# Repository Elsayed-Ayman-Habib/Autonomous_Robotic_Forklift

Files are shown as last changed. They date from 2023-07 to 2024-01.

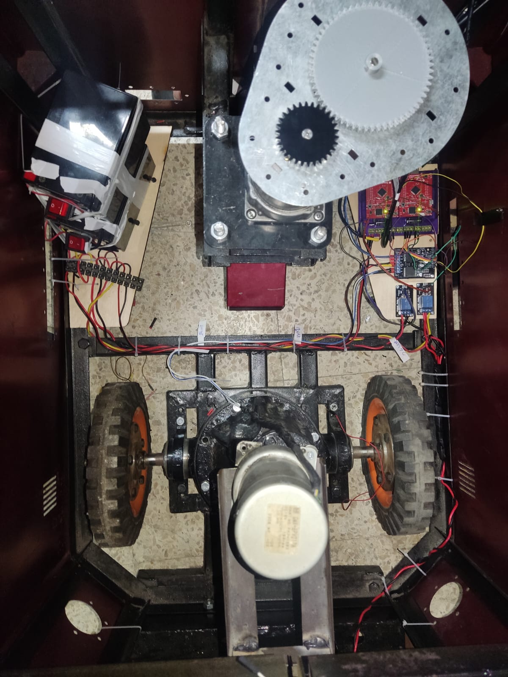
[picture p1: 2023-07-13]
Mechanical/photos/504c4e7d-c44a-4d6c-9fbc-8029b2791f7c.jpg

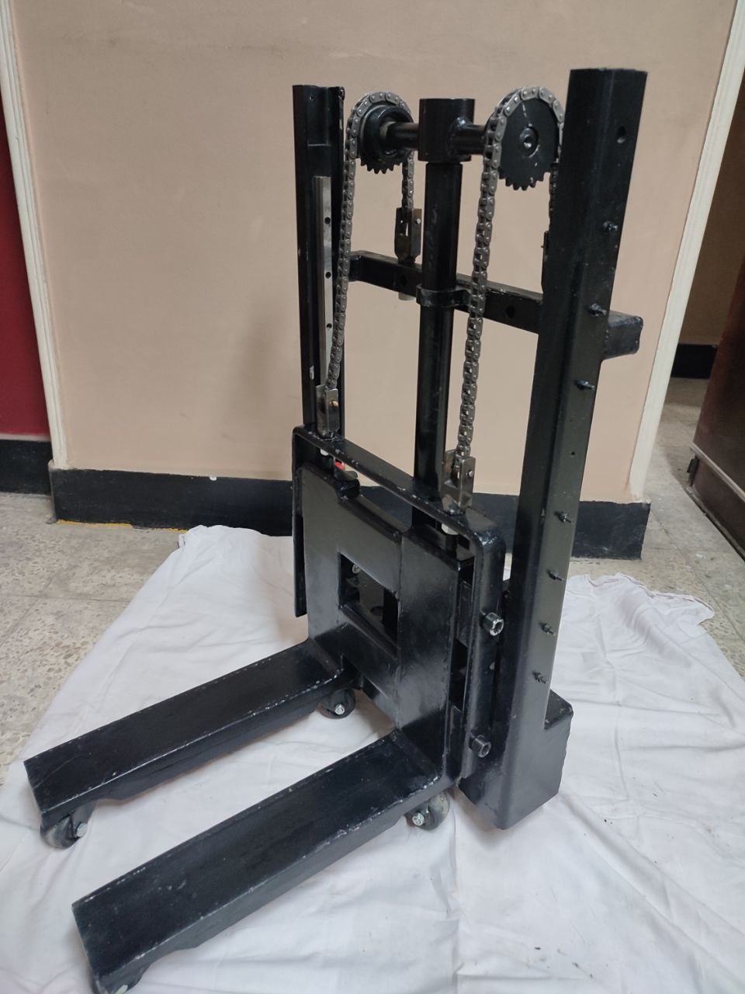
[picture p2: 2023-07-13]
Mechanical/photos/photo_2023-01-30_05-22-00.jpg

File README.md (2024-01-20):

# Autonomous_Robotic_Forklift

Our forklift prioritizes safety above all else. Its design incorporates precise sizes, tolerances, and detailed working drawings for every component. We conducted comprehensive stress analysis for optimal performance. The final product stands out with its appealing shape, exceptional finishing, and seamless assembly.

Our project involved an embedded system with one Arduino Mega microcontroller as data buffer between the Jetson TX2 and two Tiva-C boards. Following AUTOSAR standards, our system incorporated the MCAL, HAL, and APP drivers. The MCAL layer included functionalities such as DIO, PORT, ADC, PWM, INTCTRL, UART, and TIMERS, while the HAL layer focused on Encoder, Motor, and LED functionalities. The App layer featured a PID controller, parsing capabilities, and serialization techniques for efficient data transmission.

We integrated ROS for Navigation and Localization, leveraging sensor data to determine the robot's position and orientation. This framework empowered our robot to navigate complex environments with confidence, ensuring optimal path planning, obstacle avoidance, and efficient movement.

We employed computer vision techniques using a pretrained YOLO CNN for object detection and recognition. Our computer vision module included QR code detection and scanning using the zbar ROS package, enabling the robot to identify goal destinations for precise movements.

The successful integration of ROS for Navigation and Localization in our project has advanced our understanding of robotics and equipped us with the skills necessary to contribute to the future of autonomous systems. I am proud of my team's accomplishments and look forward to further exploring innovation in robotics, leveraging cutting-edge technologies like ROS to redefine human-robot interaction.

# Tutorial

### Hardware
- Nvidia Jetson TX2
- 2 Tiva-C
- Arduino Mega (as buffer)
- 2 Encoders and 2 DC motors
- Potentiometer
- Batteries (2 for system (24V-24A) - 1 for Jetson (12V-12A))
- YDLidar
- Kinect V1
- Linear Fork DC Motor
- VNH5019 DC Motor Driver
- relay module
- Emergency Stop Position

### Software
- JetPack 4.6 (For Jetson)
- Ubuntu 18.4 here.
- ROS Melodic

### 1. Setting up the Ubuntu Environment.
- 1. install sdk manager in your laptob
  2. read user guide from Nvidia jetson tx2 datasheet
  3. follow this video to complete the steps [Link of Video](https://youtu.be/Ucg5Zqm9ZMk)

### 2. Setting up the ROS repositories.
- By Opening a terminal and run the following command to configure the Ubuntu repositories:
```
sudo sh -c 'echo "deb http://packages.ros.org/ros/ubuntu $(lsb_release -sc) main" >/etc/apt/sources.list.d/ros-latest.list'
```
### 3. Setting up the ROS keys.
- By Downloading the ROS keyring and adding it to the system by running the following command:
```
curl -s https://raw.githubusercontent.com/ros/rosdistro/master/ros.asc | sudo apt-key add -
```
### 4. Updating the package lists.
- By Running the following command to update the package lists from the repositories:
```
sudo apt update
```
### 5. Desktop-Full Installation.
- ROS Melodic offers different installation options. For most users, the DesktopFull or Desktop installation is recommended as it includes the most commonly used packages for ROS development. Running the following command will install the Desktop-Full version:
```
sudo apt install ros-melodic-desktop-full
```
### 6. Initializing rosdep.
- By Running the following commands to initialize rosdep, which is used to install system dependencies for ROS packages:
```
sudo rosdep init rosdep update
```
### 7. Setting up the environment.
```
echo "source /opt/ros/melodic/setup.bash" >> ~/.bashrc source ~/.bashrc
```
### 8. Verifying the installation.
- By opening a new terminal and running the following command to check if ROS Melodic is properly installed:
```
rosversion -d
```
- The output should display melodic, confirming a successful installation

###  move_base ROS installation for Navigation stack.
- The installation commands :
```
Cd catkin_ws/src
Git clone https://github.com/ros-planning/navigation.git
```

### Teb_local_planner ROS installation. 
- The installation commands :
```
Cd catkin_ws/src
rosdep install teb_local_planner
Git clone https://github.com/rst-tu-dortmund/teb_local_planner.git
```

### robot_pose_ekf ROS installation.
- The installation commands :
```
sudo apt-get install ros-melodic-robot-pose-ekf
```

## AMCL ROS installation.
- The installation commands :
```
sudo apt-get install ros-melodic-amcl
```

### TF ROS installation.
- The installation commands:
```
Cd catkin_ws/src
Git clone https://github.com/ros/geometry
```

### installing Kinect v1 drivers and dependencies.
- Steps of installation :
 1. Install the dependencies:
```
sudo apt-get install git-core cmake freeglut3-dev pkg-config build-essential libxmu-dev libxi-dev libusb-1.0-0-dev
sudo apt-get install git-core cmake freeglut3-dev pkg-config build-essential libxmu-dev libxi-dev libusb-1.0-0-dev
```
- 2. Get the libfreenect repository from GitHub:
```
cd ~/catkin_ws/src
git clone git://github.com/OpenKinect/libfreenect.git
```
- 3. Make and install:
```
cd libfreenect
mkdir build
cd build
cmake -L ..
sudo make install
sudo ldconfig /usr/local/lib64
sudo adduser $USER video
sudo adduser $USER plugdev
```
- 4. adding some device rules:
```
sudo nano /etc/udev/rules.d/51-kinect.rules
```
- 5. generating files and running Kinect test:
```
python3 src/fwfetcher.py
sudo cp src/audios.bin /usr/local/share/libfreenect
freenect-micview
freenect-glview
```
- 6. running Kinect with ROS:
```
cd catkin_ws
catkin_make
source devel/setup
roslaunch freenect_launch freenect.launch depth_registration:=true
```

# To launch our project.
- follow this commands:
```
roslaunch freenect_launch freenect.launch depth_registration:=true
roslaunch teb_local_planner_tutorials robot_carlike_in_stage.launch #the package launch
```
# Link of Report & Presentation and Video 
- https://drive.google.com/drive/folders/1iCM8DTQ_ik3RJ6Gb64cmEPBjMHCCbpft?usp=sharing

# Final Product 


# BY:
Abdelrahman Mahmoud Ehab
Abdelrahman Mostafa Mahmoud
Abdelrhman Motawea Ali     
Abdelrahman Omar Abdelhalem  
Anas Ahmed Talaat                
El Sayed Ayman El Sayed     
Mahmoud Ayman Abdelaziz     
Mahmoud Tariq Mahmoud      
Mahmoud Nassef Mohamed      

# Thanks our Team


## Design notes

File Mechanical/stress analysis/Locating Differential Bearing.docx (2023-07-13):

Forklift Graduation Team Ainshams University January 15, 2023

Locating Differential Bearing

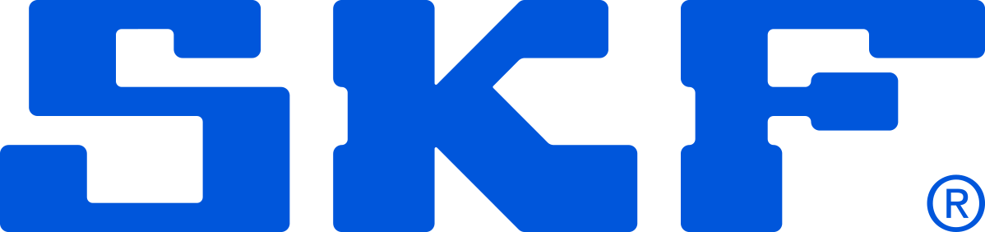
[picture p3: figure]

SKF Bearing Select Report 1.3-186

1. Abstract

Deep groove ball bearing

SKF Explorer

Calculation overview

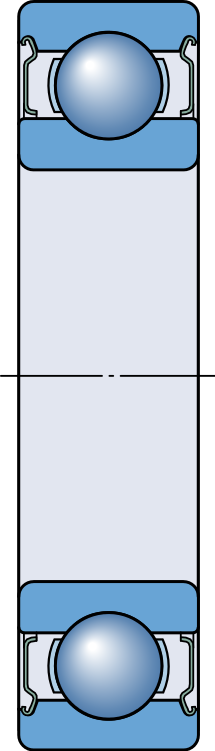
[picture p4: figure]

| Bearing | rating | life | Static safety factor | Frictional moment | Power loss
Designation | Basic | SKF life | | | Total
| L10h (h) | L10mh (h) | | S0 | M (Nmm) | Ploss (W)
6005-2Z (https://www.skf.com/productcatalogue?language=en&system=metric&designation=6005-2Z) | 5540 | 3880 | | 1.77 | 129 | 1.4

Consideration

All calculated values are best estimates resulting from the input data and assumptions, and well-recognized data sources, and well-established calculation methods.

SKF follows standards and methods suggested by Greenhouse Gas Protocol for CO2 estimates. For details about data, methods, and assumptions used, follow the link below.

If you intend to use these values for decision making, contact SKF for more details and correct interpretation of calculation results. The values calculated by SKF Bearing Select should not be compared with values obtained from other tools or sources, unless you are confident about the data sources, methods and assumptions used. More info (https://skf.com/group/support/engineering-tools/bearing-select/info-about-co2-est)

Consideration

Grease consumption is almost zero, therefore CO2 emissions are not calculated.

Consideration

The calculated SKF rating life L10 mh is shorter than the period of interest.

Consideration

Low viscosity ratio k, reduced asperity contact. It is recommended to select a higher viscosity lubricant or improve cooling. It is not appropriate to look at basic rating life only. Instead use SKF rating life method. Recommended to use anti-wear (AW) or extreme pressure (EP) additives to reduce wear More info (https://www.skf.com/group/products/rolling-bearings/principles-of-rolling-bearing-selection/bearing-selection-process/bearing-size/size-selection-based-on-rat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)

Rotating ring Inner ring rotation

Maximum temperature is used for calculating the actual viscosity, kappa, aSKF and SKF rating life. Mean temperature is used for calculating bearing friction and power loss.

2.2. Loads, Speed and Temperature

2. Input

2.1. Bearing data

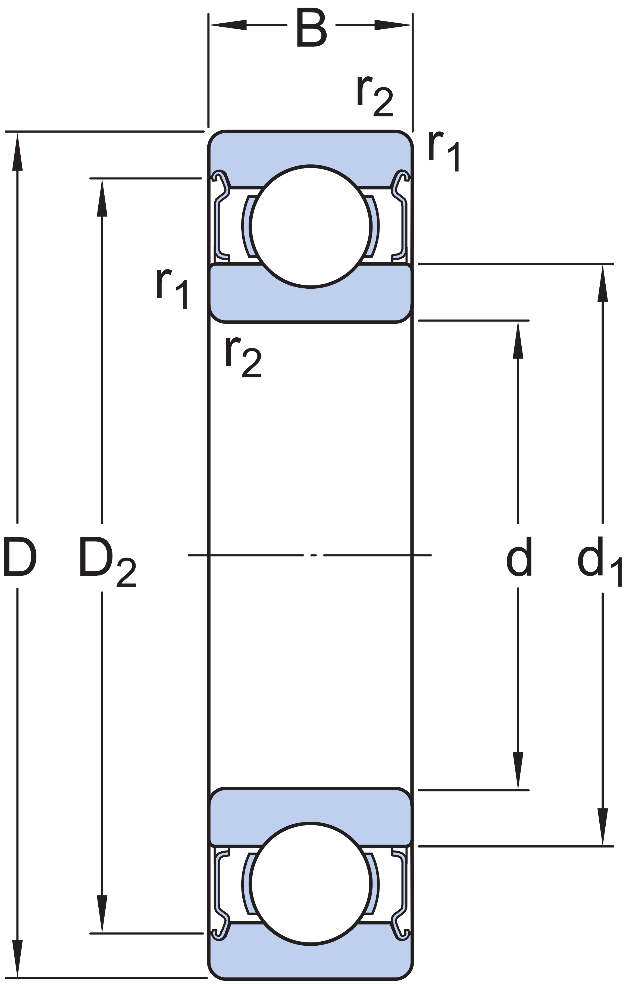
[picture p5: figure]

| | Principal | dimensions | | Basic load | ratings | Fatigue load limit | Speed ratings | | Cleara nce class
Designation | Bearing type | | | | Dynamic | Static | | Reference | Limiting
| | d (mm) | D (mm) | B (mm) | C (kN) | C0 (kN) | Pu (kN) | nref (r/min) | nlim (r/min)
6005-2Z (https://www.skf.com/productcatalogue?language=en&system=metric&designation=6005-2Z) | Deep ball groove bearing | 25.0 | 47.0 | 12.0 | 11.9 | 6.55 | 0.275 | 32000.0 | 16000.0 | Norma l

Forces | | | | | | Speed | Temperature | | | | Case weight
Radial | | ( Fr | ) | (kN) | Axial ( Fa ) (kN) | (r/min) | Inner | ring | (°C) | Outer ring (°C)
LC1 | 3.7 | 0.0 | | | | 100.0 | 30 | 30 | | | 1

2.3. Lubrication
| | | Lubricant | Effective EP additives | Contamination
| | Designation | Name | | Method | Cleanliness / Factor
| 6005-2Z (https://www.skf.com/productcatalogue?language=en&system=metric&designation=6005-2Z) | | MT47 | False | Detailed guidelines | High cleanliness

3.2. Bearing minimum load

3.3. Adjusted reference speed

2.4. CO2 emissions settings
| Designation | Input energy mix manually | Geographical location | Period of interest [Years] | Time operational [%]
| 6005-2Z (https://www.skf.com//opcprodlink.html?lang=language_Report&imperial=metric&prodid=6005-2Z) | False | European Union | 1 | 100

2.5. Fits and tolerances
| | | Requirements | Tolerance | Class | Calculated interference | Include Smoothing
| | Designation | Guidance | Housing | Shaft
| 6005-2Z (https://www.skf.com/productcatalogue?language=en&system=metric&designation) | | False | G7 | g6 | True | True

3. Results

3.1. Loads & static safety
| | | Load | ratio | Static safety factor | Equivalent dynamic load | Equivalent static load
| | Designation | C/P | S0 | | P (kN) | P0 (kN)
| 6005-2Z (https://www.skf.com/productcatalogue?language=en&system=metric&designation=6005-2Z) | | 3.22 | 1.77 | | 3.7 | 3.7

| | Reaction | forces Minimum load
| Designation | Radial | Axial | | Requirements
| | Fr (kN) | Fa (kN) | Frm (kN) | met?
6005-2Z (https://www.skf.com/productcatalogue?language=en&system=metric&designation=6005-2Z) | | 3.7 | 0.0 | 0.0177 | yes

| | Adjusted reference speed | Adjustment | factors
| Designation | | For bearing | load | P | For oil viscosity
| | nar (r/min) | fp | fv
6005-2Z (https://www.skf.com/productcatalogue?language=en&system=metric&designation=6005-2Z) | | 13700 | 0.41 | 1.03

3.4. Lubrication conditions

3.5. Bearing rating life

3.7. Bearing frequencies

| | Frictional moment Friction sources | | | | | | | | Power loss
| Designation | Total | At start and 20-30°C zero speed | | Rolling | Sliding | Seals | | Drag loss
| | M (Nmm) | Mstart | (Nmm) | Mrr (Nmm) | Msl (Nmm) | Mseal | (Nmm) | Mdrag (Nmm) | Ploss (W)
6005-2Z (https://www.skf.com/productcatalogue?language=en&system=metric&designation=6005-2Z) | | 129 | 195 | 11.1 | | 118 | 0 | 0 | | 1.4

| | Operating viscosity | | | Viscosity ratio
| Designation | Actual | Rated | Rated @ 40 °C
| | ν (mm^2/s) | ν1 (mm^2/s) | νref (mm^2/s) | κ
6005-2Z (https://www.skf.com/productcatalogue?language=en&system=metric&designation=6005-2Z) | | 128 | 147 | 85.0 | 0.87

| | Bearing | rating | life | SKF life modification factor | Contamination factor
| Designation | Basic | SKF
| | L10h (h) | L10mh (h) | | askf | ηc
6005-2Z (https://www.skf.com/productcatalogue?language=en&system=metric&designation=6005-2Z) | | 5540 | 3880 | | 0.7 | 0.45

Consideration

Low viscosity ratio k, reduced asperity contact. It is recommended to select a higher viscosity lubricant or improve cooling. It is not appropriate to look at basic rating life only. Instead use SKF rating life method. Recommended to use anti-wear (AW) or extreme pressure (EP) additives to reduce wear More info (https://www.skf.com/group/products/rolling-bearings/principles-of-rolling-bearing-selection/bearing-selection-process/bearing-size/size-selection-based-on-rat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)

3.6. Bearing friction & power loss

| Rotational frequencies | | | | | | | Frequency of over-rolling
Designation | Inner | ring | Outer ring | Rolling & cage | element | set | Rolling element about its axis | Point on inner ring | Point on outer ring | Rolling | element
| fi (Hz) | fe (Hz) | | fc (Hz) | fr (Hz) | | | fip (Hz) | fep (Hz) | frp (Hz)
6005-2Z (https://www.skf.com/productcatalogue?language=en&system=metric&designation=6005-2Z) | 1.667 | 0.0 | | 0.677 | 4.29 | | | 9.895 | 6.772 | 8.58

* Value is not designation specific, but based on bearing mass

3.8. Estimation of CO2 emissions over period of interest

| Shaft outer | diameter | Bearing bore | | Bearing outer diameter | | Housing bore | | Smoothing
Designation | Minimum | Maximum | Minimum | Maximum | Minimum | Maximum | Minimum | Maximum | Shaft an bearing | d bore | Bearing outer ring and housing
| (μm) | (μm) | (μm) | (μm) | (μm) | (μm) | (μm) | (μm) | (μm) | (μm)
6005-2Z (https://www.skf.com/productcatalogue?language=en&system=metric&designation=6005-2Z) | -20 | -7 | -10 | 0 | -11 | 0 | 9 | 34 | 7 | 12

| | CO2 emissions caused by bearing production | CO2 emissions during bearing operation - over period of interest | | | | Resources consumed during bearing operation - over period of interest
| Designation | | Frictio power | nal loss | Grease c onsumpt ion | Sum of CO2 o during peration | Energy | Grease
| | kg of CO2 | kg of | CO2 | kg of CO2 | kg of CO2 | kWh | kg
6005-2Z (https://www.skf.com/productcatalogue?language=en&system=metric&designation=6005-2Z) | | *0.3 (Learn more) (https://skf.com/group/support/engineering-tools/bearing-select/info-about-co2-est#cid-596137) | 5.5 | 0.0 | | 5.5 | 11.9 | 0.0

Consideration

All calculated values are best estimates resulting from the input data and assumptions, and well-recognized data sources, and well-established calculation methods.

SKF follows standards and methods suggested by Greenhouse Gas Protocol for CO2 estimates. For details about data, methods, and assumptions used, follow the link below.

If you intend to use these values for decision making, contact SKF for more details and correct interpretation of calculation results. The values calculated by SKF Bearing Select should not be compared with values obtained from other tools or sources, unless you are confident about the data sources, methods and assumptions used. More info (https://skf.com/group/support/engineering-tools/bearing-select/info-about-co2-est)

Consideration

Grease consumption is almost zero, therefore CO2 emissions are not calculated.

Consideration

The calculated SKF rating life L10 mh is shorter than the period of interest.

3.9. Fits and tolerances
| Note Typically, it is not sufficient to use an interference fit alone to axially locate a bearing ring on a cylindrical seat.

3.9.1. Tolerances

Consideration

For the tolerances calculation, the normal tolerance for the bearing bore and outer diameter is used.

3.9.2. Fits, Probable Interference (+) / Clearance (-)

| | Shaft | | | Housing
| Designation | Probable minimum | Middle | Probable maximum | Probable minimum | Middle | Probable maximum
| | (μm) | (μm) | (μm) | (μm) | (μm) | (μm)
6005-2Z (https://www.skf.com/productcatalogue?language=en&system=metric&designation=6005-2Z) | | -24 | -16 | -7 | -53 | -39 | -25

SKF Bearing Select 6 2023-01-15 16:31:43

LIMITED WARRANTY : The SKF Bearing Select software tool of the SKF Company supports the calculation and selection of bearings.

This software is provided 'as is' with out any warranty of any sort, implicitly as well as explicitly.

Please note that the obtained results can be affected by many external parameters and/or the quality of the assumptions taken into account. The results obtained using this software must be validated by the user who accepts the fact that the use of this software and the exploitation of the obtained results are under the user's entire and sole responsibility.

® SKF is a registered trademark of the SKF Group. © SKF Group 2022.

SKF Bearing Select 1 2023-01-15 16:31:43 This report was produced with SKF Bearing Select software. Please note the limited warranty, shown at the bottom of the last page of this report ® SKF is a registered trademark of the SKF Group. © SKF Group 2022.

SKF Bearing Select 2 2023-01-15 16:31:43 This report was produced with SKF Bearing Select software. Please note the limited warranty, shown at the bottom of the last page of this report ® SKF is a registered trademark of the SKF Group. © SKF Group 2022.

SKF Bearing Select Report 1.3-186

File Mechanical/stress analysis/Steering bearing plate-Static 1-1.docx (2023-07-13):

# Loads and Fixtures

Fixture name | Fixture Image | Fixture Details

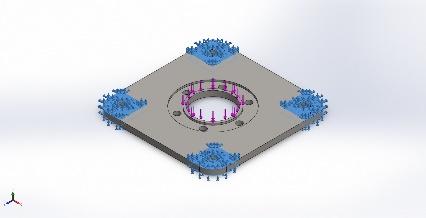
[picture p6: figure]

Fixed-1 | | Entities: 8 face(s) Type: Fixed Geometry

Resultant Forces

Components | X | Y | Z | Resultant
Reaction force(N) | -0.16123 | 2,499.99 | -0.136569 | 2,499.99
Reaction Moment(N.m) | 0 | 0 | 0 | 0

Load name | Load Image | Load Details

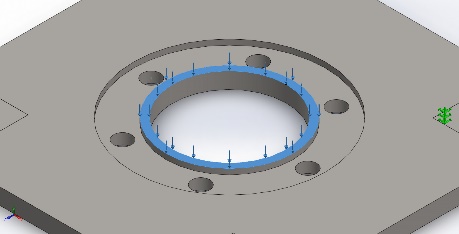
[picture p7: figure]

Force-1 | | Entities: 1 face(s) Type: Apply normal force Value: 2,500 N

# Resultant Forces :

## Reaction forces :

Selection set | Units | Sum X | Sum Y | Sum Z | Resultant
Entire Model | N | -0.16123 | 2,499.99 | -0.136569 | 2,499.99

## Reaction Moments :

Selection set | Units | Sum X | Sum Y | Sum Z | Resultant
Entire Model | N.m | 0 | 0 | 0 | 0

## Free body forces :

Selection set | Units | Sum X | Sum Y | Sum Z | Resultant
Entire Model | N | 0.19792 | 1.8234 | 0.393877 | 1.87593

## Free body moments :

Selection set | Units | Sum X | Sum Y | Sum Z | Resultant
Entire Model | N.m | 0 | 0 | 0 | 1e-33

# Study Results

Name | Type | Min | Max
Stress1 | VON: von Mises Stress | 4.504e-04N/mm^2 (MPa) Node: 9706 | 1.010e+02N/mm^2 (MPa) Node: 20652

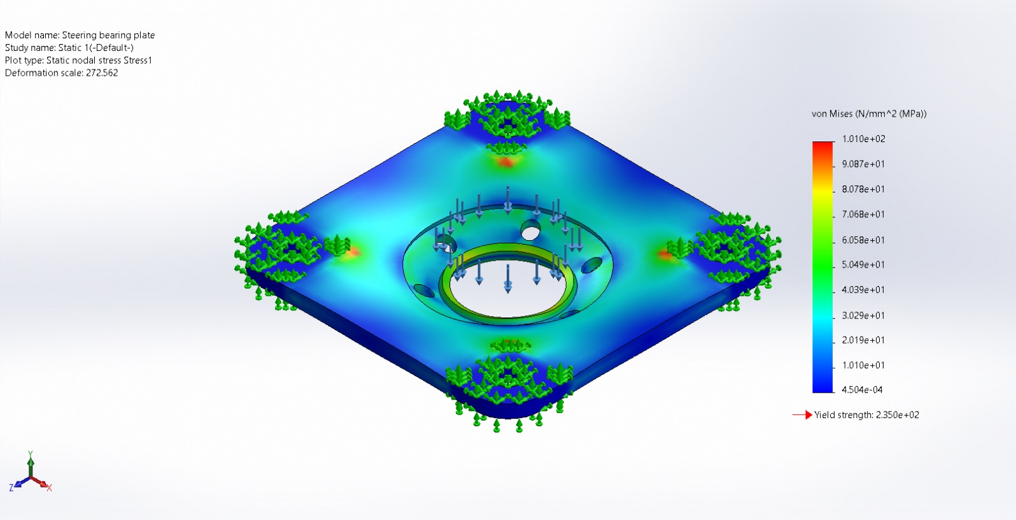
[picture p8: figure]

Steering bearing plate-Static 1-Stress-Stress1

Name | Type | Min | Max
Displacement1 | URES: Resultant Displacement | 0.000e+00mm Node: 1 | 4.806e-02mm Node: 363

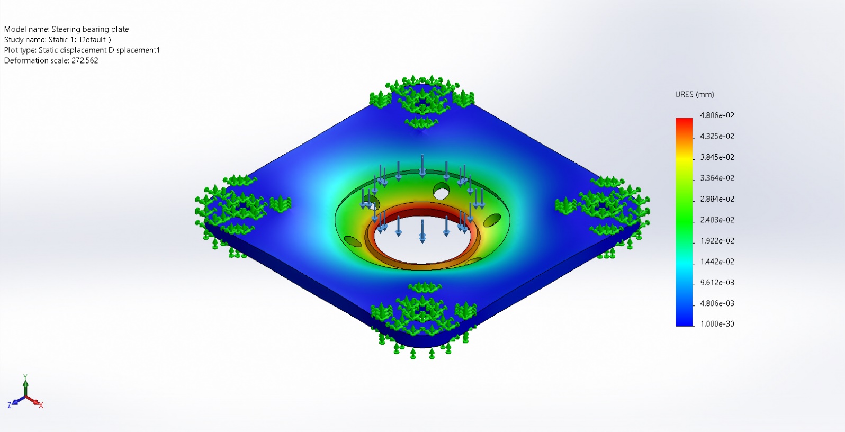
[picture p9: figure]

Steering bearing plate-Static 1-Displacement-Displacement1

Name | Type | Min | Max
Strain1 | ESTRN: Equivalent Strain | 1.795e-09 Element: 3587 | 2.801e-04 Element: 12603

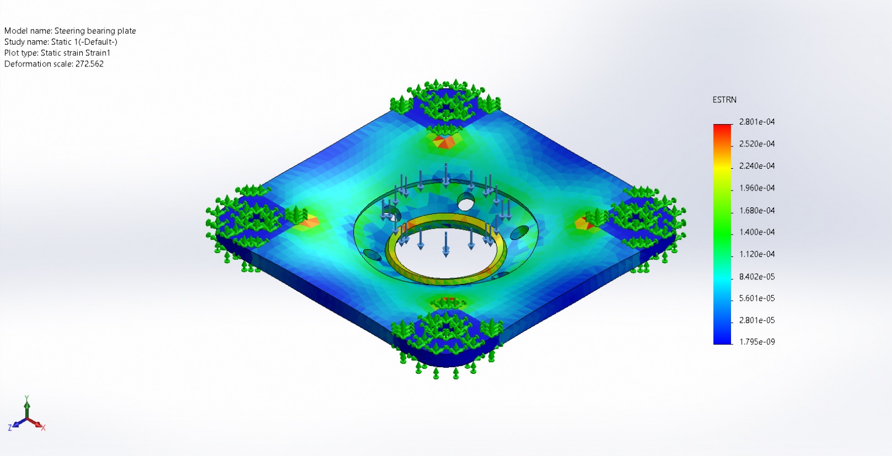
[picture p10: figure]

Steering bearing plate-Static 1-Strain-Strain1

Analyzed with SOLIDWORKS Simulation Simulation of Steering bearing plate 16

Analyzed with SOLIDWORKS Simulation Simulation of Steering bearing plate 1

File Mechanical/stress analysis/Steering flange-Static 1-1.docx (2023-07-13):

# Loads and Fixtures

Fixture name | Fixture Image | Fixture Details

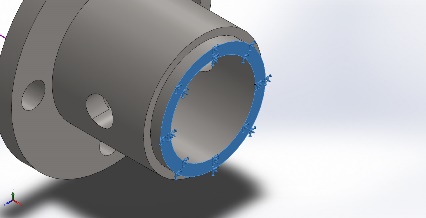
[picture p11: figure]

Fixed-1 | | Entities: 1 face(s) Type: Fixed Geometry

Resultant Forces

Components | X | Y | Z | Resultant
Reaction force(N) | -2,500.02 | 0.0202789 | -0.0246192 | 2,500.02
Reaction Moment(N.m) | 0 | 0 | 0 | 0

Load name | Load Image | Load Details

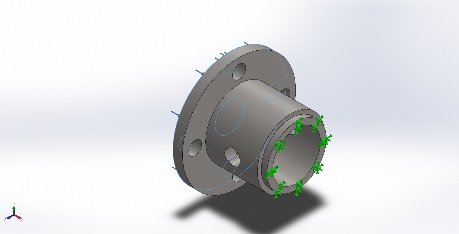
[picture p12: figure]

Force-1 | | Entities: 1 face(s) Type: Apply normal force Value: 2,500 N

# Resultant Forces :

## Reaction forces :

Selection set | Units | Sum X | Sum Y | Sum Z | Resultant
Entire Model | N | -2,500.02 | 0.0202789 | -0.0246192 | 2,500.02

## Reaction Moments :

Selection set | Units | Sum X | Sum Y | Sum Z | Resultant
Entire Model | N.m | 0 | 0 | 0 | 0

## Free body forces :

Selection set | Units | Sum X | Sum Y | Sum Z | Resultant
Entire Model | N | 0.047928 | 0.103331 | 0.163004 | 0.198859

## Free body moments :

Selection set | Units | Sum X | Sum Y | Sum Z | Resultant
Entire Model | N.m | 0 | 0 | 0 | 1e-33

# Study Results

Name | Type | Min | Max
Stress1 | VON: von Mises Stress | 1.890e-01N/mm^2 (MPa) Node: 26868 | 2.419e+01N/mm^2 (MPa) Node: 17132

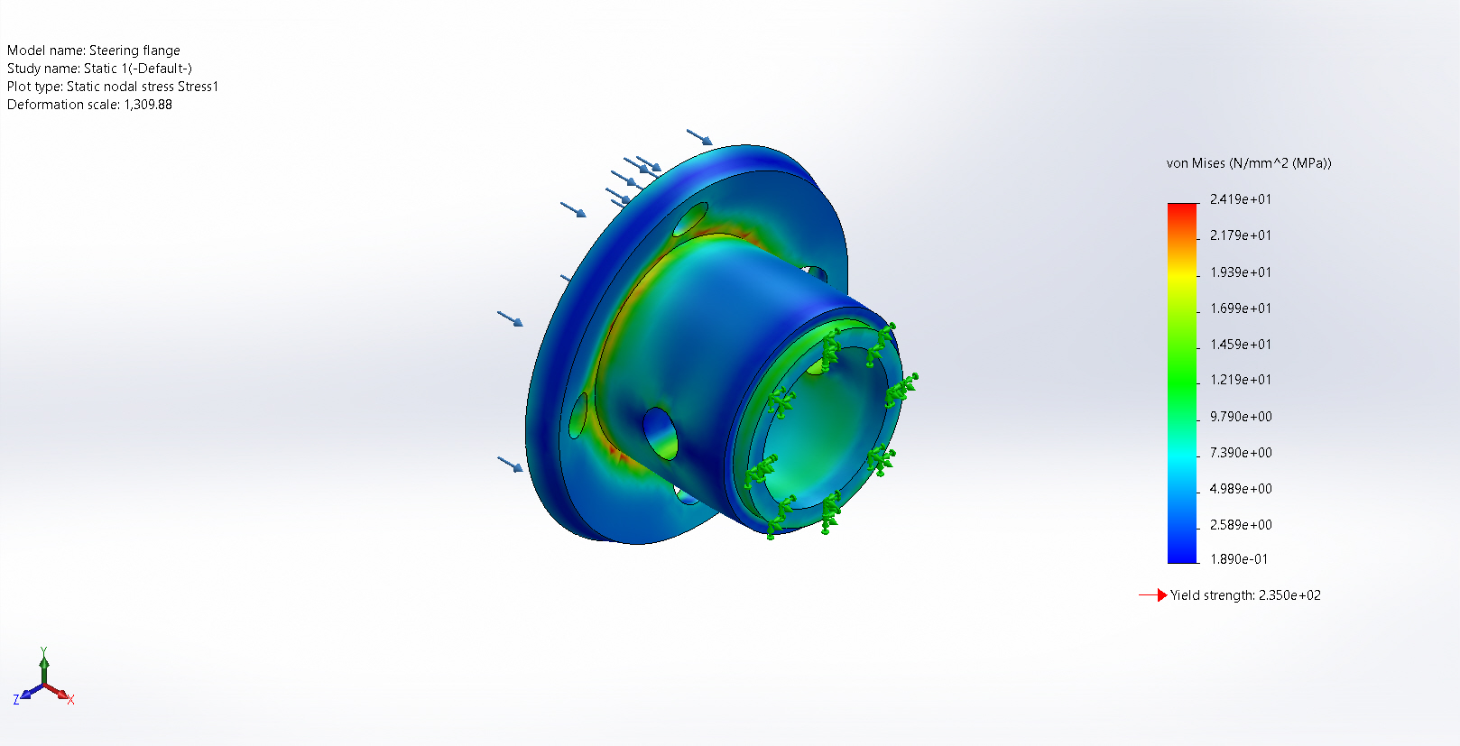
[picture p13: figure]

Steering flange-Static 1-Stress-Stress1

Name | Type | Min | Max
Displacement1 | URES: Resultant Displacement | 0.000e+00mm Node: 785 | 4.579e-03mm Node: 25194

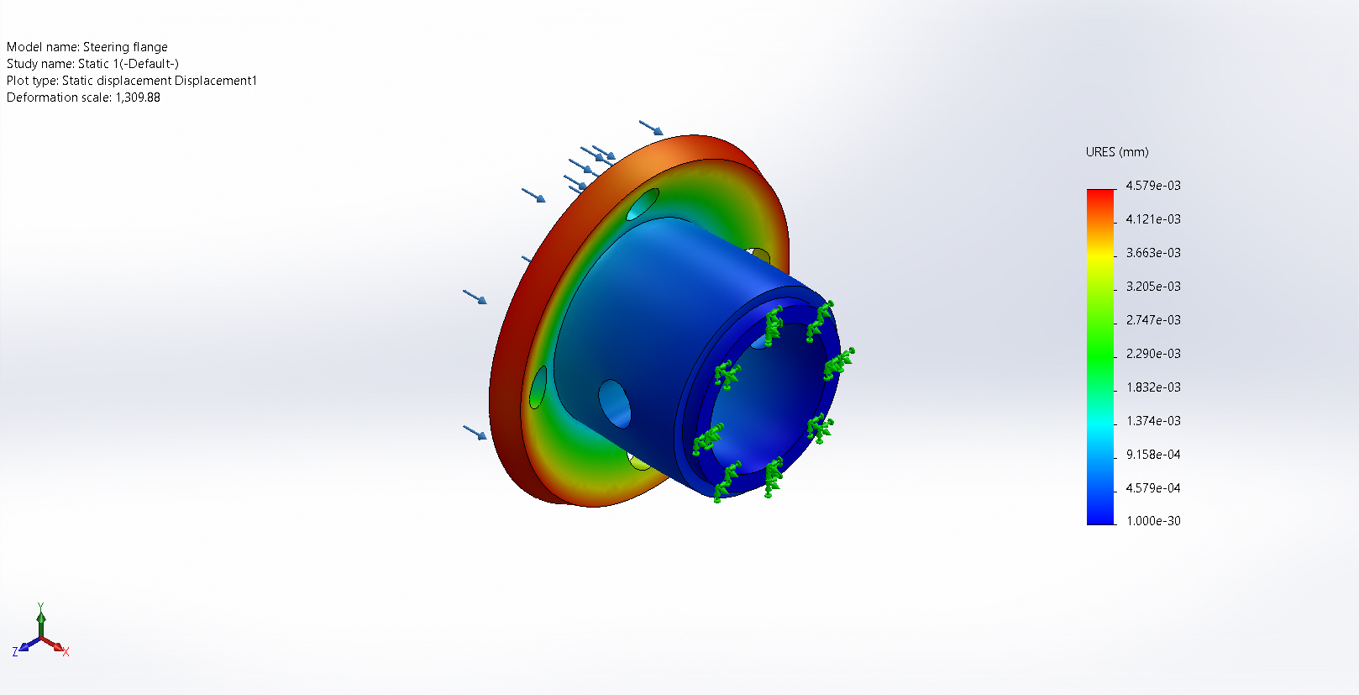
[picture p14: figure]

Steering flange-Static 1-Displacement-Displacement1

Name | Type | Min | Max
Strain1 | ESTRN: Equivalent Strain | 1.079e-06 Element: 2479 | 9.309e-05 Element: 9469

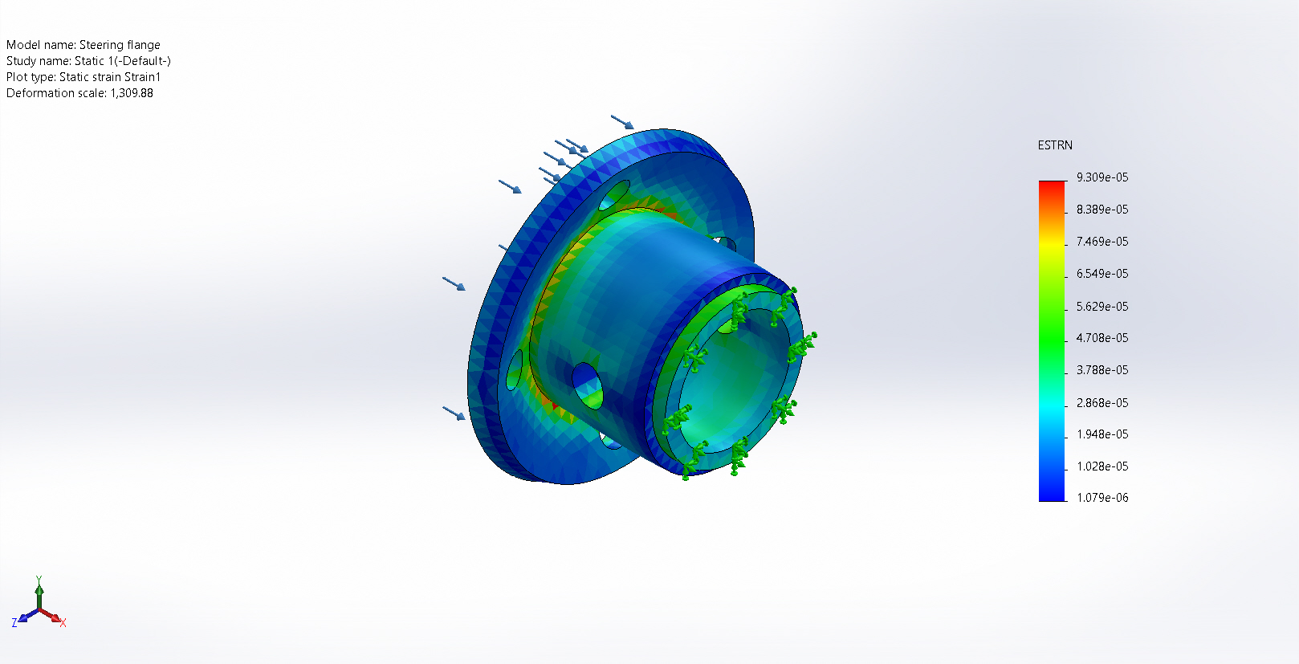
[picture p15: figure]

Steering flange-Static 1-Strain-Strain1

Analyzed with SOLIDWORKS Simulation Simulation of Steering flange 16

Analyzed with SOLIDWORKS Simulation Simulation of Steering flange 1

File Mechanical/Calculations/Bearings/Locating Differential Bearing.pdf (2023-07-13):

Forklift Graduation Team

Ainshams University

January 15, 2023

Locating Differential Bearing

2023-01-15 16:31:43

SKF Bearing Select Report 1.3-186

# 1. Abstract

## Calculation overview

Deep groove ball bearing

SKF Explorer

Bearing rating life | Static safety
factor

Frictional
| | | | moment | Power loss
Designation | Basic | SKF life | | Total
| L
| 10h (h) | L
| | 10mh (h) | S
| | | 0 | M (Nmm) | P loss (W)
6005-2Z (https://www.skf.com/productcatalogue?language=en&system=metric&designation=6005-2Z) | 5540 | 3880 | 1.77 | 129 | 1.4

### Consideration

All calculated values are best estimates resulting from the input data and assumptions, and well-recognized data sources, and well-established calculation methods.
SKF follows standards and methods suggested by Greenhouse Gas Protocol for CO2

estimates.
For details about data, methods, and assumptions used, follow the link below.
If you intend to use these values for decision making, contact SKF for more details and correct interpretation of calculation results. The values calculated by SKF Bearing Select should not be compared with values obtained from other tools or sources, unless you are confident about the data sources, methods and assumptions used. More info (https://skf.com/group/support/engineering-tools/bearing-select/info-about-co2-est)

### Consideration

Grease consumption is almost zero, therefore CO2

emissions are not calculated.

### Consideration

The calculated SKF rating life L10 mh is shorter than the period of interest.

### Consideration

Low viscosity ratio k, reduced asperity contact. It is recommended to select a higher viscosity lubricant or improve cooling. It is not appropriate to look at basic rating life only. Instead use SKF rating life method. Recommended to use anti-wear (AW) or extreme pressure (EP) additives to reduce wear More info (https://www.skf.com/group/products/rolling-bearings/principles-of-rolling-bearing-selection/bearing-selection-process/bearing-size/size-selection-based-on-rat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)

SKF Bearing Select | 1

This report was produced with SKF Bearing Select software. Please note the limited warranty, shown at the bottom of the last page of this report
| ® SKF is a registered trademark of the SKF Group. © SKF Group 2022.

2023-01-15 16:31:43

# 2. Input

## 2.1. Bearing data

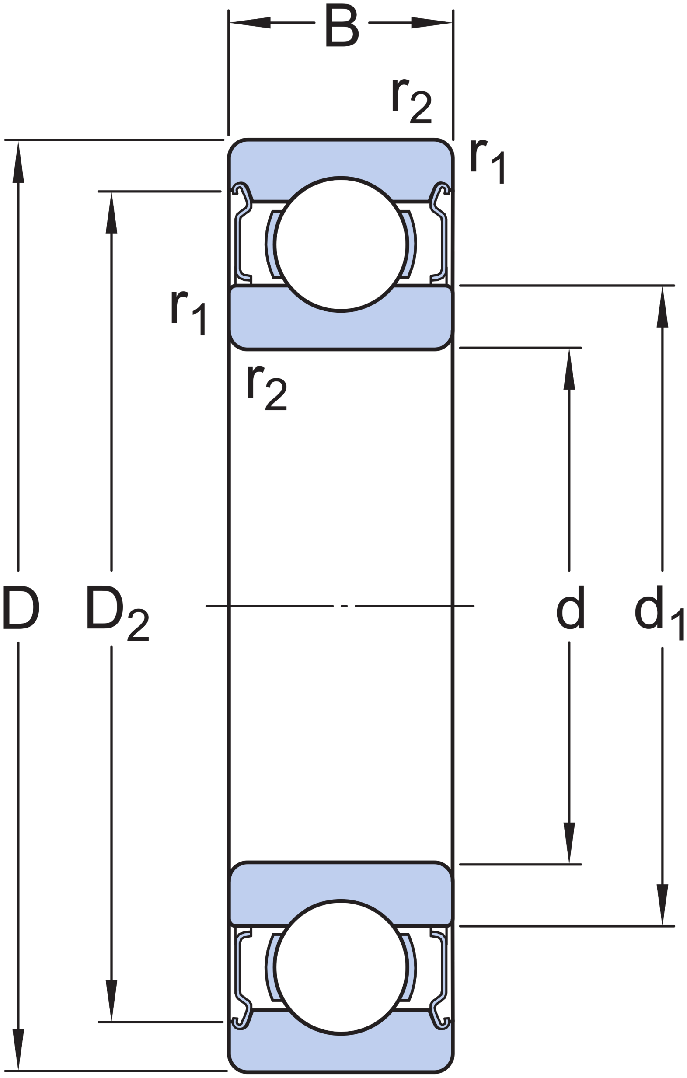
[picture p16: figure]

Principal dimensions | Basic load ratings | Fatigue load
| | | | | limit | Speed ratings | | Cleara nce class
Designation | Bearing
type | Dynamic | Static | Reference | Limiting
d (mm) | D (mm) | B (mm) | C (kN) | C
| | | | 0
| | | | (kN) | P u
| | | | | (kN) | n
| | | | | | ref (r/min) | n lim (r/min)

6005-2Z (https://www.skf.com/productcatalogue?language=en&system=metric&designation=6005-2Z)

Deep
groove ball
bearing
25.0 | 47.0 | 12.0 | 11.9 | 6.55 | 0.275 | 32000.0 | 16000.0 | Norma l

## 2.2. Loads, Speed and Temperature

Rotating ring | | Inner ring rotation
| Forces | | Speed | Temperature | | Case weight
| Radial ( F
r

) (kN) Axial ( F
a
) (kN) | (r/min) | Inner ring (°C) | Outer ring (°C)
LC1 | 3.7 | 0.0 | 100.0 | 30 | 30 | 1

Maximum temperature is used for calculating the actual viscosity, kappa, aSKF and SKF rating life.

Mean temperature is used for calculating bearing friction and power loss.

## 2.3. Lubrication

Lubricant | Effective EP
| | | additives | Contamination
Designation | Name | Method | Cleanliness / Factor
6005-2Z (https://www.skf.com/productcatalogue?language=en&system=metric&designation=6005-2Z) | MT47 | False | Detailed guidelines | High cleanliness
SKF Bearing Select | 2

This report was produced with SKF Bearing Select software. Please note the limited warranty, shown at the bottom of the last page of this report

2023-01-15 16:31:43

2.4. CO2

## emissions settings

Designation | Input energy mix manually | Geographical location | Period of interest [Years] | Time operational [%]
6005-2Z (https://www.skf.com//opcprodlink.html?lang=language_Report&imperial=metric&prodid=6005-2Z) | False | European Union | 1 | 100

## 2.5. Fits and tolerances

| Requirements | Tolerance Class | | Calculated
| | | | interference | Include Smoothing
Designation | Guidance | Housing | Shaft
6005-2Z (https://www.skf.com/productcatalogue?language=en&system=metric&designation=) | False | G7 | g6 | True | True

# 3. Results

## 3.1. Loads & static safety

| Load ratio | Static safety
| | factor | Equivalent dynamic load | | Equivalent static load
Designation | C/P | S
0
P (kN) | P
0

(kN)

6005-2Z (https://www.skf.com/productcatalogue?language=en&system=metric&designation=6005-2Z) | 3.22 | 1.77 | 3.7 | 3.7

## 3.2. Bearing minimum load

| Reaction forces | Minimum load
Designation | Radial | Axial | Requirements

F
r
(kN) | F
a
(kN) | F
rm
(kN) | met?
6005-2Z (https://www.skf.com/productcatalogue?language=en&system=metric&designation=6005-2Z) | 3.7 | 0.0 | 0.0177 | yes

## 3.3. Adjusted reference speed

| Adjusted reference
| speed | Adjustment factors
Designation | | For bearing load P | | For oil viscosity
| n
| ar
| (r/min) | f
p

f
v
6005-2Z (https://www.skf.com/productcatalogue?language=en&system=metric&designation=6005-2Z) | 13700 | 0.41 | 1.03
SKF Bearing Select | 3

This report was produced with SKF Bearing Select software. Please note the limited warranty, shown at the bottom of the last page of this report

2023-01-15 16:31:43

## 3.4. Lubrication conditions

Operating viscosity | Viscosity ratio
Designation | Actual | | Rated | Rated @ 40 °C
ν (mm^2/s) | ν
1
(mm^2/s) | ν
ref (mm^2/s) | κ
6005-2Z (https://www.skf.com/productcatalogue?language=en&system=metric&designation=6005-2Z) | 128 | 147 | 85.0 | 0.87

## 3.5. Bearing rating life

Bearing rating life | SKF life modification
factor | Contamination factor
Designation | Basic | | SKF
| L
10h (h) | L
10mh (h) | a
| | | skf | | η
| | | | | c
6005-2Z (https://www.skf.com/productcatalogue?language=en&system=metric&designation=6005-2Z) | 5540 | 3880 | 0.7 | 0.45

### Consideration

Low viscosity ratio k, reduced asperity contact. It is recommended to select a higher viscosity lubricant or improve cooling. It is not appropriate to look at basic rating life only. Instead use SKF rating life method. Recommended to use anti-wear (AW) or extreme pressure (EP) additives to reduce wear More info (https://www.skf.com/group/products/rolling-bearings/principles-of-rolling-bearing-selection/bearing-selection-process/bearing-size/size-selection-based-on-rat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)

## 3.6. Bearing friction & power loss

Frictional moment | Friction sources | Power
| | | | | | | loss
Designation | Total | At start
20-30°C and
zero speed
| | | Rolling | Sliding | Seals | Drag loss
M (Nmm) | Mstart (Nmm) | Mrr
(Nmm) | Msl (Nmm) | Mseal (Nmm) | Mdrag (Nmm) | P
| | | | | | | loss (W)
6005-2Z (https://www.skf.com/productcatalogue?language=en&system=metric&designation=6005-2Z) | 129 | 195 | 11.1 | 118 | 0 | 0 | 1.4

## 3.7. Bearing frequencies

Rotational frequencies | Frequency of over-rolling
Designation | Inner ring | Outer ring | Rolling element set
| | | & cage | Rolling element
| | | | about its axis | Point on
| | | | | inner ring | Point on
| | | | | | outer ring | Rolling element
| f
| i
| (Hz) | f
| | e
| | (Hz) | f
| | | c
| | | (Hz) | f
| | | | r
| | | | (Hz) | f
| | | | | ip (Hz) | f
| | | | | | ep
| | | | | | (Hz) | f
| | | | | | | rp (Hz)
6005-2Z (https://www.skf.com/productcatalogue?language=en&system=metric&designation=6005-2Z) | 1.667 | 0.0 | 0.677 | 4.29 | 9.895 | 6.772 | 8.58
SKF Bearing Select | 4

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

2023-01-15 16:31:43

## 3.8. Estimation of CO2

## emissions over period of interest

CO2

emissions caused
by bearing production

CO2

emissions during bearing
operation - over period of interest

Resources consumed during
bearing operation - over period of interest
Designation | Frictional
power loss

Grease c
onsumpt
ion

Sum of
CO2
during o
peration
Energy | Grease

kg of CO2

kg of CO2

kg of
CO2

kg of
CO2
kWh | kg
6005-2Z (https://www.skf.com/productcatalogue?language=en&system=metric&designation=6005-2Z) | *
0.3 (Learn more) (https://skf.com/group/support/engineering-tools/bearing-select/info-about-co2-est#cid-596137) | 5.5 | 0.0 | 5.5 | 11.9 | 0.0

*
Value is not designation specific, but based on bearing mass

### Consideration

All calculated values are best estimates resulting from the input data and assumptions, and well-recognized data sources, and well-established calculation methods.
SKF follows standards and methods suggested by Greenhouse Gas Protocol for CO2

estimates.
For details about data, methods, and assumptions used, follow the link below.
If you intend to use these values for decision making, contact SKF for more details and correct interpretation of calculation results. The values calculated by SKF Bearing Select should not be compared with values obtained from other tools or sources, unless you are confident about the data sources, methods and assumptions used. More info (https://skf.com/group/support/engineering-tools/bearing-select/info-about-co2-est)

### Consideration

Grease consumption is almost zero, therefore CO2

emissions are not calculated.

### Consideration

The calculated SKF rating life L10 mh is shorter than the period of interest.

## 3.9. Fits and tolerances

### Note

Typically, it is not sufficient to use an interference fit alone to axially locate a bearing ring on a cylindrical seat.

## 3.9.1. Tolerances

Shaft outer diameter | Bearing bore | Bearing outer
diameter | Housing bore | Smoothing
Designation | Minimum | Maximum | Minimum | Maximum | Minimum | Maximum | Minimum | Maximum | Shaft and bearing bore | Bearing outer ring and housing
| (μm) | (μm) | (μm) | (μm) | (μm) | (μm) | (μm) | (μm) | (μm) | (μm)
6005-2Z (https://www.skf.com/productcatalogue?language=en&system=metric&designation=6005-2Z) | -20 | -7 | -10 | 0 | -11 | 0 | 9 | 34 | 7 | 12

### Consideration

For the tolerances calculation, the normal tolerance for the bearing bore and outer diameter is used.

SKF Bearing Select | 5

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

2023-01-15 16:31:43

## 3.9.2. Fits, Probable Interference (+) / Clearance (-)

Shaft | Housing
Designation | Probable
minimum | Middle | Probable maximum

Probable

| | | | minimum | Middle | Probable maximum
| (μm) | (μm) | (μm) | (μm) | (μm) | (μm)
6005-2Z (https://www.skf.com/productcatalogue?language=en&system=metric&designation=6005-2Z) | -24 | -16 | -7 | -53 | -39 | -25
SKF Bearing Select | 6

LIMITED WARRANTY : The SKF Bearing Select software tool of the SKF Company supports the calculation and selection of bearings.
| This software is provided 'as is' with out any warranty of any sort, implicitly as well as explicitly.
Please note that the obtained results can be affected by many external parameters and/or the quality of the assumptions taken into account. The results obtained using this software must be validated by the user who accepts the fact that the use of this software and the exploitation
| of the obtained results are under the user's entire and sole responsibility.

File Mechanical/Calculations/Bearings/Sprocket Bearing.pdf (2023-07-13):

Forklift Graduation Team

Ainshams University

January 15, 2023

Sprocket Bearing

2023-01-15 14:47:45

SKF Bearing Select Report 1.3-186

# 1. Abstract

## Calculation overview

Deep groove ball bearing

SKF Explorer

Bearing rating life | Grease | Static safety
factor

Frictional
| | | | | moment | Power loss
Designation | Basic | SKF life | Catalogue grease
| | | life | | Total
| L
| 10h (h) | L
| | 10mh (h) | L
| | | 10 (h) | S
| | | | 0 | M (Nmm) | P loss (W)
6004-2Z (https://www.skf.com/productcatalogue?language=en&system=metric&designation=6004-2Z) | 102000 | 13400 | 43700 | 2.5 | 58.9 | 0.12

### Consideration

Grease consumption is almost zero, therefore CO2

emissions are not calculated.

### Consideration

All calculated values are best estimates resulting from the input data and assumptions, and well-recognized data sources, and well-established calculation methods.
SKF follows standards and methods suggested by Greenhouse Gas Protocol for CO2

estimates.
For details about data, methods, and assumptions used, follow the link below.
If you intend to use these values for decision making, contact SKF for more details and correct interpretation of calculation results. The values calculated by SKF Bearing Select should not be compared with values obtained from other tools or sources, unless you are confident about the data sources, methods and assumptions used. More info (https://skf.com/group/support/engineering-tools/bearing-select/info-about-co2-est)

### Consideration

Low viscosity ratio k, reduced asperity contact. It is recommended to select a higher viscosity lubricant or improve cooling. It is not appropriate to look at basic rating life only. Instead use SKF rating life method. Recommended to use anti-wear (AW) or extreme pressure (EP) additives to reduce wear More info (https://www.skf.com/group/products/rolling-bearings/principles-of-rolling-bearing-selection/bearing-selection-process/bearing-size/size-selection-based-on-rat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)

SKF Bearing Select | 1

This report was produced with SKF Bearing Select software. Please note the limited warranty, shown at the bottom of the last page of this report
| ® SKF is a registered trademark of the SKF Group. © SKF Group 2022.

2023-01-15 14:47:45

# 2. Input

## 2.1. Bearing data


Principal dimensions | Basic load ratings | Fatigue load
| | | | | limit | Speed ratings | | Cleara nce class
Designation | Bearing
type | Dynamic | Static | Reference | Limiting
d (mm) | D (mm) | B (mm) | C (kN) | C
| | | | 0
| | | | (kN) | P u
| | | | | (kN) | n
| | | | | | ref (r/min) | n lim (r/min)

6004-2Z (https://www.skf.com/productcatalogue?language=en&system=metric&designation=6004-2Z)

Deep
groove ball
bearing
20.0 | 42.0 | 12.0 | 9.95 | 5.0 | 0.212 | 38000.0 | 19000.0 | Norma l

## 2.2. Loads, Speed and Temperature

Shaft orientation | Horizontal
Rotating ring | | Inner ring rotation
| Forces | | Speed | Temperature | | Case weight
| Radial ( F
r

) (kN) Axial ( F
a
) (kN) | (r/min) | Inner ring (°C) | Outer ring (°C)
LC1 | 2.0 | 0.0 | 20.0 | 30 | 30 | 1

Maximum temperature is used for calculating the actual viscosity, kappa, aSKF and SKF rating life.

Mean temperature is used for calculating bearing friction and power loss.

## 2.3. Lubrication

Lubricant | Effective EP
| | | additives | Contamination
Designation | Name | Method | Cleanliness / Factor
6004-2Z (https://www.skf.com/productcatalogue?language=en&system=metric&designation=6004-2Z) | MT47 | False | Detailed guidelines | High cleanliness
SKF Bearing Select | 2

This report was produced with SKF Bearing Select software. Please note the limited warranty, shown at the bottom of the last page of this report

2023-01-15 14:47:45

2.4. CO2

## emissions settings

Designation | Input energy mix manually | Geographical location | Period of interest [Years] | Time operational [%]
6004-2Z (https://www.skf.com//opcprodlink.html?lang=language_Report&imperial=metric&prodid=6004-2Z) | False | European Union | 1 | 100

## 2.5. Fits and tolerances

| Requirements | Tolerance Class | | Calculated
| | | | interference | Include Smoothing
Designation | Guidance | Housing | Shaft
6004-2Z (https://www.skf.com/productcatalogue?language=en&system=metric&designation=) | False | J7 | j6 | True | True

# 3. Results

## 3.1. Loads & static safety

| Load ratio | Static safety
| | factor | Equivalent dynamic load | | Equivalent static load
Designation | C/P | S
0
P (kN) | P
0

(kN)

6004-2Z (https://www.skf.com/productcatalogue?language=en&system=metric&designation=6004-2Z) | 4.97 | 2.5 | 2.0 | 2

## 3.2. Bearing minimum load

| Reaction forces | Minimum load
Designation | Radial | Axial | Requirements

F
r
(kN) | F
a
(kN) | F
rm
(kN) | met?
6004-2Z (https://www.skf.com/productcatalogue?language=en&system=metric&designation=6004-2Z) | 2.0 | 0.0 | 0.0045 | yes

## 3.3. Adjusted reference speed

| Adjusted reference
| speed | Adjustment factors
Designation | | For bearing load P | | For oil viscosity
| n
| ar
| (r/min) | f
p

f
v
6004-2Z (https://www.skf.com/productcatalogue?language=en&system=metric&designation=6004-2Z) | 22800 | 0.56 | 1.07
SKF Bearing Select | 3

This report was produced with SKF Bearing Select software. Please note the limited warranty, shown at the bottom of the last page of this report

2023-01-15 14:47:45

## 3.4. Lubrication conditions

Operating viscosity | Viscosity ratio
Designation | Actual | Rated | | Rated @ 40 °C
| ν (mm^2/s) | ν
1
(mm^2/s) | ν
ref (mm^2/s) | κ
6004-2Z (https://www.skf.com/productcatalogue?language=en&system=metric&designation=6004-2Z) | 128 | 640 | 332 | 0.19

## 3.5. Grease life and relubrication interval

Catalogue grease life | Speed factor
Designation | | | Speed x mean diameter
| L
10 (h) | nd
m
| | | (mm/min)
6004-2Z (https://www.skf.com/productcatalogue?language=en&system=metric&designation=6004-2Z) | 43700 | 620

## 3.6. Bearing rating life

Bearing rating life | SKF life modification
factor | Contamination factor
Designation | Basic | SKF
| L
| 10h (h) | L
10mh (h) | a
skf | η
c
6004-2Z (https://www.skf.com/productcatalogue?language=en&system=metric&designation=6004-2Z) | 102000 | 13400 | 0.13 | | 0.15

### Consideration

Low viscosity ratio k, reduced asperity contact. It is recommended to select a higher viscosity lubricant or improve cooling. It is not appropriate to look at basic rating life only. Instead use SKF rating life method. Recommended to use anti-wear (AW) or extreme pressure (EP) additives to reduce wear More info (https://www.skf.com/group/products/rolling-bearings/principles-of-rolling-bearing-selection/bearing-selection-process/bearing-size/size-selection-based-on-rat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)

## 3.7. Bearing friction & power loss

Frictional moment | Friction sources | Power
| | | | | | | loss
Designation | Total | At start 20-30°C and zero speed | Rolling | Sliding | Seals | Drag loss
| M (Nmm) | Mstart (Nmm) | Mrr
(Nmm) | Msl (Nmm) | Mseal (Nmm) | Mdrag (Nmm) | P
| | | | | | | loss (W)
6004-2Z (https://www.skf.com/productcatalogue?language=en&system=metric&designation=6004-2Z) | 58.9 | 72.7 | 2.3 | 56.6 | 0 | 0 | 0.12
SKF Bearing Select | 4

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

2023-01-15 14:47:45

## 3.8. Bearing frequencies

Rotational frequencies | Frequency of over-rolling
Designation | Inner ring | Outer ring | Rolling element set
| | | & cage | Rolling element
| | | | about its axis | Point on
| | | | | inner ring | Point on
| | | | | | outer ring | Rolling element
| f
| i
| (Hz) | f
| | e
| | (Hz) | f
| | | c
| | | (Hz) | f
| | | | r
| | | | (Hz) | f
| | | | | ip (Hz) | f
| | | | | | ep
| | | | | | (Hz) | f
| | | | | | | rp (Hz)
6004-2Z (https://www.skf.com/productcatalogue?language=en&system=metric&designation=6004-2Z) | 0.333 | 0.0 | 0.133 | 0.78 | 1.807 | 1.193 | 1.559

## 3.9. Estimation of CO2

## emissions over period of interest

CO2

emissions caused
by bearing production

CO2

emissions during bearing
operation - over period of interest

Resources consumed during
bearing operation - over period of interest
Designation | Frictional
power loss

Grease c
onsumpt
ion

Sum of
CO2
during o
peration
Energy | Grease

kg of CO2

kg of CO2

kg of
CO2

kg of
CO2
| | | | kWh | kg
6004-2Z (https://www.skf.com/productcatalogue?language=en&system=metric&designation=6004-2Z) | *
0.3 (Learn more) (https://skf.com/group/support/engineering-tools/bearing-select/info-about-co2-est#cid-596137) | 0.5 | 0.0 | 0.5 | 1.08 | 0.0

*
Value is not designation specific, but based on bearing mass

### Consideration

Grease consumption is almost zero, therefore CO2

emissions are not calculated.

### Consideration

All calculated values are best estimates resulting from the input data and assumptions, and well-recognized data sources, and well-established calculation methods.
SKF follows standards and methods suggested by Greenhouse Gas Protocol for CO2
| | | | estimates.
For details about data, methods, and assumptions used, follow the link below.
If you intend to use these values for decision making, contact SKF for more details and correct interpretation of calculation results. The values calculated by SKF Bearing Select should not be compared with values obtained from other tools or sources, unless you are confident about the data sources, methods and assumptions used. More info (https://skf.com/group/support/engineering-tools/bearing-select/info-about-co2-est)
SKF Bearing Select | 5

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

2023-01-15 14:47:45

## 3.10. Fits and tolerances

### Note

Typically, it is not sufficient to use an interference fit alone to axially locate a bearing ring on a cylindrical seat.

## 3.10.1. Tolerances

Shaft outer diameter | Bearing bore | Bearing outer
diameter | Housing bore | Smoothing
Designation | Minimum | Maximum | Minimum | Maximum | Minimum | Maximum | Minimum | Maximum | Shaft and bearing bore | Bearing outer ring and housing
| (μm) | (μm) | (μm) | (μm) | (μm) | (μm) | (μm) | (μm) | (μm) | (μm)
6004-2Z (https://www.skf.com/productcatalogue?language=en&system=metric&designation=6004-2Z) | -4 | 9 | -10 | 0 | -11 | 0 | -11 | 14 | 7 | 12

### Consideration

For the tolerances calculation, the normal tolerance for the bearing bore and outer diameter is used.

## 3.10.2. Fits, Probable Interference (+) / Clearance (-)

Shaft | Housing
Designation | Probable
minimum | Middle | Probable maximum

Probable

| | | | minimum | Middle | Probable maximum
| (μm) | (μm) | (μm) | (μm) | (μm) | (μm)
6004-2Z (https://www.skf.com/productcatalogue?language=en&system=metric&designation=6004-2Z) | -8 | 1 | 9 | -33 | -19 | -5
SKF Bearing Select | 6

LIMITED WARRANTY : The SKF Bearing Select software tool of the SKF Company supports the calculation and selection of bearings.
| This software is provided 'as is' with out any warranty of any sort, implicitly as well as explicitly.
Please note that the obtained results can be affected by many external parameters and/or the quality of the assumptions taken into account. The results obtained using this software must be validated by the user who accepts the fact that the use of this software and the exploitation
| of the obtained results are under the user's entire and sole responsibility.

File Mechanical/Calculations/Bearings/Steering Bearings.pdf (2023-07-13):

Forklift Graduation Team

Ainshams University

January 15, 2023

Steering Bearings

2023-01-15 14:38:32

SKF Bearing Select Report 1.2-76

# 1. Abstract

## Calculation overview

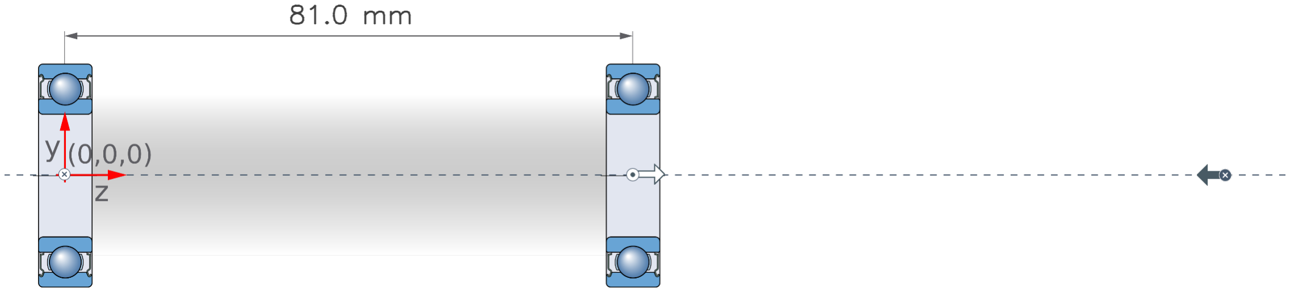
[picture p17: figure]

Deep groove ball bearing | Deep groove ball bearing
| | Non-Locating | | | | Locating
| | | | | | SKF Explorer
| | Bearing rating life | | Grease | Static safety
| | | | | factor | Frictional
| | | | | | moment | Power loss
| Designation | Basic | SKF life | Catalogue
| | | | grease life | | Total
| | L
| | 10h (h) | L
| | | 10mh (h) | L
| | | | 10 (h) | S
| | | | | 0 | M (Nmm) | P loss (W)
Left | 6004-2Z (https://www.skf.com/productcatalogue?language=en&system=metric&designation=6004-2Z) | > 2x10^5 | > 2x10^5 | 80100 | 13.8 | 4.75 | 0.03
Right | 6005-2Z (https://www.skf.com/productcatalogue?language=en&system=metric&designation=6005-2Z) | 20200 | 8510 | 17000 | 4.29 | 181 | 1.1

Left bearing
Consideration
All calculated values are best estimates resulting from the input data and assumptions, and well-recognized data sources, and well-established calculation methods.
SKF follows standards and methods suggested by Greenhouse Gas Protocol for CO2
| | | | | estimates.
For details about data, methods, and assumptions used, follow the link below.
If you intend to use these values for decision making, contact SKF for more details and correct interpretation of calculation results. The values calculated by SKF Bearing Select should not be compared with values obtained from other tools or sources, unless you are confident about the data sources, methods and assumptions used. More info (https://skf.com/group/support/engineering-tools/bearing-select/info-about-co2-est)

Consideration
Grease consumption is almost zero, therefore CO2

emissions are not calculated.

Consideration
Low viscosity ratio k, reduced asperity contact. It is recommended to select a higher viscosity lubricant or improve cooling. It is not appropriate to look at basic rating life only. Instead use SKF rating life method. Recommended to use anti-wear (AW) or extreme pressure (EP) additives to reduce wear More info (https://www.skf.com/group/products/rolling-bearings/principles-of-rolling-bearing-selection/bearing-selection-process/bearing-size/size-selection-based-on-rat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)

Consideration
For rating life results above 100000 hours, other failure modes than those included in the current rating life models will dominate and limit the life of the bearing.

Right bearing
Consideration
Grease consumption is almost zero, therefore CO2

emissions are not calculated.

SKF Bearing Select | 1

This report was produced with SKF Bearing Select software. Please note the limited warranty, shown at the bottom of the last page of this report
| ® SKF is a registered trademark of the SKF Group. © SKF Group 2022.

2023-01-15 14:38:32

Consideration
All calculated values are best estimates resulting from the input data and assumptions, and well-recognized data sources, and well-established calculation methods.
SKF follows standards and methods suggested by Greenhouse Gas Protocol for CO2

estimates.
For details about data, methods, and assumptions used, follow the link below.
If you intend to use these values for decision making, contact SKF for more details and correct interpretation of calculation results. The values calculated by SKF Bearing Select should not be compared with values obtained from other tools or sources, unless you are confident about the data sources, methods and assumptions used. More info (https://skf.com/group/support/engineering-tools/bearing-select/info-about-co2-est)

Consideration
Low viscosity ratio k, reduced asperity contact. It is recommended to select a higher viscosity lubricant or improve cooling. It is not appropriate to look at basic rating life only. Instead use SKF rating life method. Recommended to use anti-wear (AW) or extreme pressure (EP) additives to reduce wear More info (https://www.skf.com/group/products/rolling-bearings/principles-of-rolling-bearing-selection/bearing-selection-process/bearing-size/size-selection-based-on-rat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)

# 2. Input

## 2.1. Bearing data

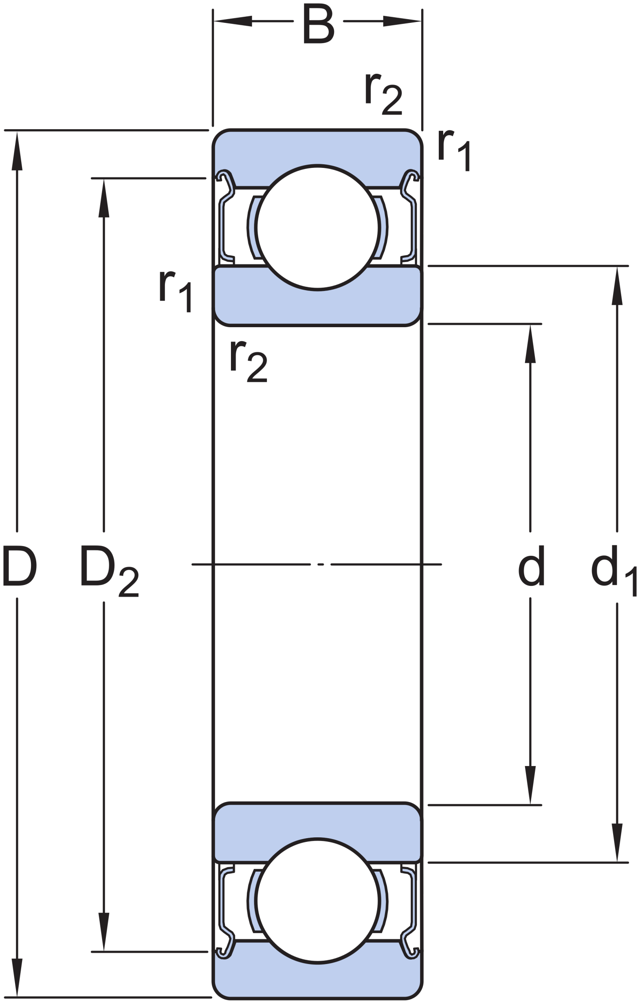
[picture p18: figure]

Bearing type | Principal dimensions | Basic load ratings | Fatigue load
limit | Speed ratings | Clearance
class
Designation | Dynamic Static | Reference Limiting
d (mm) D (mm) B (mm) | C (kN) | C
0
| | | | | (kN) | P u
| | | | | | (kN) | n

ref (r/min) n

| | | | | | | | lim (r/min)
Left | 6004-2Z (https://www.skf.com/productcatalogue?language=en&system=metric&designation=6004-2Z) | Deep groove
ball bearing | 20.0 | 42.0 | 12.0 | 9.95 | 5.0 | 0.212 | 38000.0 | 19000.0 | Normal
Right | 6005-2Z (https://www.skf.com/productcatalogue?language=en&system=metric&designation=6005-2Z) | Deep groove
ball bearing | 25.0 | 47.0 | 12.0 | 11.9 | 6.55 | 0.275 | 32000.0 | 16000.0 | Normal
SKF Bearing Select | 2

This report was produced with SKF Bearing Select software. Please note the limited warranty, shown at the bottom of the last page of this report

2023-01-15 14:38:32

## 2.2. Loads & Speed

Locating | 1
Bearing distance | 81.0 | mm
Shaft orientation | Vertical
Rotating ring | Inner ring rotation

Coordinate
system | Coordinates | Forces | Speed | Case
weight
Load | x|r (mm) y|θ (mm|deg) | z (mm) | Fx|Fr (kN) | Fy|Fθ (kN) | Fz (kN) | (r/min)
LC1 | F1 | Cartesian | 0.0 | 0.0 | 375.0 | 0.1 | 0.0 | -2.5 | 60.0 | 1

## 2.3. Temperature

Left | Right
Load cases | Inner ring (°C) | Outer ring (°C) | Inner ring (°C) | Outer ring (°C)
LC1 | 30 | 30 | 30 | 30

Maximum temperature is used for calculating the actual viscosity, kappa, aSKF and SKF rating life.

Mean temperature is used for calculating bearing friction and power loss.

## 2.4. Lubrication

Lubricant | Effective EP additives | Contamination
Designation | Name | Method | Cleanliness / Factor
Left | 6004-2Z (https://www.skf.com/productcatalogue?language=en&system=metric&designation=6004-2Z) | MT47 | False | Detailed guidelines | High cleanliness
Right | 6005-2Z (https://www.skf.com/productcatalogue?language=en&system=metric&designation=6005-2Z) | MT47 | False | Detailed guidelines | High cleanliness
2.5. CO2

## emissions settings

| Designation | Input energy mix
| | manually | Geographical location | Period of interest [Years] | Time
| | | | | operational
| | | | | [%]
Left | 6004-2Z (https://www.skf.com/productcatalogue?language=en&system=metric&designation=6004-2Z) | False | European Union | 1 | 100
Right | 6005-2Z (https://www.skf.com/productcatalogue?language=en&system=metric&designation=6005-2Z) | False | European Union | 1 | 100
SKF Bearing Select | 3

This report was produced with SKF Bearing Select software. Please note the limited warranty, shown at the bottom of the last page of this report

2023-01-15 14:38:32

## 2.6. Fits and tolerances

| | Requirements | Tolerance Class | | Calculated
| | | | | interference | Include Smoothing
| Designation | Guidance | Housing | Shaft
Left | 6004-2Z (https://www.skf.com/productcatalogue?language=en&system=metric&designation=6004-2Z) | False | G7 | g6 | True | True
Right | 6005-2Z (https://www.skf.com/productcatalogue?language=en&system=metric&designation=6005-2Z) | False | G7 | g6 | True | True
SKF Bearing Select | 4

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

2023-01-15 14:38:32

# 3. Results

## 3.1. Loads & static safety

Load ratio | Static safety
factor | Equivalent dynamic load | Equivalent static load
| Designation | C/P | S
| | | 0 | P (kN) | P
| | | | | 0 (kN)
Left | 6004-2Z (https://www.skf.com/productcatalogue?language=en&system=metric&designation=6004-2Z) | 27.41 | 13.8 | 0.36 | 0.363
Right | 6005-2Z (https://www.skf.com/productcatalogue?language=en&system=metric&designation=6005-2Z) | 4.18 | 4.29 | 2.85 | 1.53

## 3.2. Bearing minimum load

Reaction forces | Minimum load
| Designation | Radial | Axial | | Requirements
| | F r
| | (kN) | F a
| | | (kN) | F rm
| | | | (kN) | met?
Left | 6004-2Z (https://www.skf.com/productcatalogue?language=en&system=metric&designation=6004-2Z) | 0.363 | 0 | 0.00936 | yes
Right | 6005-2Z (https://www.skf.com/productcatalogue?language=en&system=metric&designation=6005-2Z) | 0.463 | 2.5 | 0.0126 | yes

## 3.3. Adjusted reference speed

Adjusted reference speed | Adjustment factors
Designation | For bearing load P | For oil viscosity
| | n ar
| | (r/min) | | f p | f v
Left | 6004-2Z (https://www.skf.com/productcatalogue?language=en&system=metric&designation=6004-2Z) | 43200 | | 0.97 | 1.18
Right | 6005-2Z (https://www.skf.com/productcatalogue?language=en&system=metric&designation=6005-2Z) | 17400 | | 0.52 | 1.06

## 3.4. Lubrication conditions

Operating viscosity | Viscosity ratio
Designation | Actual | Rated | Rated @ 40 °C
| | ν (mm^2/s) | ν
| | | 1
(mm^2/s) | ν
ref (mm^2/s) | κ
Left | 6004-2Z (https://www.skf.com/productcatalogue?language=en&system=metric&designation=6004-2Z) | 128 | 247 | 137 | 0.51
Right | 6005-2Z (https://www.skf.com/productcatalogue?language=en&system=metric&designation=6005-2Z) | 128 | 229 | 128 | 0.55
SKF Bearing Select | 5

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

2023-01-15 14:38:32

## 3.5. Grease life and relubrication interval

Catalogue grease
| | life | Speed factor
| Designation | | Speed x mean
| | | diameter
| | L
| | 10 (h) | nd
| | | m (mm/min)
Left | 6004-2Z (https://www.skf.com/productcatalogue?language=en&system=metric&designation=6004-2Z) | 80100 | 1860
Right | 6005-2Z (https://www.skf.com/productcatalogue?language=en&system=metric&designation=6005-2Z) | 17000 | 2160

## 3.6. Bearing rating life

Bearing rating life

SKF life
modification
factor

Contamination
factor
| Designation | Basic | | SKF
| | L
| | 10h (h) | | L
10mh (h) | a
skf | η
c
Left | 6004-2Z (https://www.skf.com/productcatalogue?language=en&system=metric&designation=6004-2Z) | > 2x10^5 | | > 2x10^5 | | 1.19 | 0.29
Right | 6005-2Z (https://www.skf.com/productcatalogue?language=en&system=metric&designation=6005-2Z) | 20200 | | 8510 | | 0.42 | 0.33

Left bearing
Consideration
Low viscosity ratio k, reduced asperity contact. It is recommended to select a higher viscosity lubricant or improve cooling. It is not appropriate to look at basic rating life only. Instead use SKF rating life method. Recommended to use anti-wear (AW) or extreme pressure (EP) additives to reduce wear More info (https://www.skf.com/group/products/rolling-bearings/principles-of-rolling-bearing-selection/bearing-selection-process/bearing-size/size-selection-based-on-rat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)

Consideration
For rating life results above 100000 hours, other failure modes than those included in the current rating life models will dominate and limit the life of the bearing.

Right bearing
Consideration
Low viscosity ratio k, reduced asperity contact. It is recommended to select a higher viscosity lubricant or improve cooling. It is not appropriate to look at basic rating life only. Instead use SKF rating life method. Recommended to use anti-wear (AW) or extreme pressure (EP) additives to reduce wear More info (https://www.skf.com/group/products/rolling-bearings/principles-of-rolling-bearing-selection/bearing-selection-process/bearing-size/size-selection-based-on-rat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)

## 3.7. Bearing friction & power loss

Frictional moment | Friction sources | Power
| | | | | | | | loss
| Designation | Total | At start 20-30°C and zero speed | Rolling | Sliding | Seals | Drag loss
| | M (Nmm) | Mstart (Nmm) | Mrr
| | | | (Nmm) | Msl (Nmm) | Mseal (Nmm) | Mdrag (Nmm) | P loss (W)
Left | 6004-2Z (https://www.skf.com/productcatalogue?language=en&system=metric&designation=6004-2Z) | 4.75 | 4.23 | 1.76 | 2.99 | 0 | 0 | 0.03
Right | 6005-2Z (https://www.skf.com/productcatalogue?language=en&system=metric&designation=6005-2Z) | 181 | 238 | 16.4 | 165 | 0 | 0 | 1.1
SKF Bearing Select | 6

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

2023-01-15 14:38:32

## 3.8. Bearing frequencies

Rotational frequencies | Frequency of over-rolling
Designation | Inner ring | Outer ring Rolling element
set & cage

Rolling element
about its axis

Point on inner
ring

Point on outer
| | | | | | | ring | Rolling element
| | f
| | i
| | (Hz) | f
| | | e
| | | (Hz) | f
| | | | c
| | | | (Hz) | f
| | | | | r
| | | | | (Hz) | f
| | | | | | ip (Hz) | f
| | | | | | | ep
| | | | | | | (Hz) | f
| | | | | | | | rp (Hz)
Left | 6004-2Z (https://www.skf.com/productcatalogue?language=en&system=metric&designation=6004-2Z) | 1.0 | 0.0 | 0.398 | 2.339 | 5.422 | 3.578 | 4.677
Right | 6005-2Z (https://www.skf.com/productcatalogue?language=en&system=metric&designation=6005-2Z) | 1.0 | 0.0 | 0.406 | 2.574 | 5.937 | 4.063 | 5.148

## 3.9. Estimation of CO2

## emissions over period of interest

CO2

emissions caused
by bearing production

CO2

emissions during bearing operation -over period of interest

Resources consumed during
bearing operation - over period of interest
Designation | Frictional
power loss

Grease
consumption

Sum of
CO2

during
operation
| | | | Energy | Grease
kg of CO2 | kg of CO2 | kg of CO2 | kg of CO2 | kWh | kg
Left | 6004-2Z (https://www.skf.com/productcatalogue?language=en&system=metric&designation=6004-2Z) | *
0.3 (Learn more) (https://skf.com/group/support/engineering-tools/bearing-select/info-about-co2-est#cid-596137) | 0.1 | 0.0 | 0.1 | 0.26 | 0.0
Right | 6005-2Z (https://www.skf.com/productcatalogue?language=en&system=metric&designation=6005-2Z) | *
0.3 (Learn more) (https://skf.com/group/support/engineering-tools/bearing-select/info-about-co2-est#cid-596137) | 4.6 | 0.0 | 4.6 | 10.0 | 0.0

*
Value is not designation specific, but based on bearing mass
Left bearing
Consideration
All calculated values are best estimates resulting from the input data and assumptions, and well-recognized data sources, and well-established calculation methods.
SKF follows standards and methods suggested by Greenhouse Gas Protocol for CO2
| | | estimates.
For details about data, methods, and assumptions used, follow the link below.
If you intend to use these values for decision making, contact SKF for more details and correct interpretation of calculation results. The values calculated by SKF Bearing Select should not be compared with values obtained from other tools or sources, unless you are confident about the data sources, methods and assumptions used. More info (https://skf.com/group/support/engineering-tools/bearing-select/info-about-co2-est)

Consideration
Grease consumption is almost zero, therefore CO2

emissions are not calculated.

Right bearing
Consideration
Grease consumption is almost zero, therefore CO2

emissions are not calculated.

Consideration
All calculated values are best estimates resulting from the input data and assumptions, and well-recognized data sources, and well-established calculation methods.
SKF follows standards and methods suggested by Greenhouse Gas Protocol for CO2
| | | estimates.
For details about data, methods, and assumptions used, follow the link below.
If you intend to use these values for decision making, contact SKF for more details and correct interpretation of calculation results. The values calculated by SKF Bearing Select should not be compared with values obtained from other tools or sources, unless you are confident about the data sources, methods and assumptions used. More info (https://skf.com/group/support/engineering-tools/bearing-select/info-about-co2-est)
SKF Bearing Select | 7

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

2023-01-15 14:38:32

## 3.10. Fits and tolerances

## 3.10.1. Tolerances

Shaft outer diameter | Bearing bore | Bearing outer
diameter | Housing bore | Smoothing

Designatio
n

Minimum Maximum Minimu
m
Maximum | Minimum Maximum | Minimum Maximum | Shaft and
bearing bore

Bearing outer
ring and housing
| (μm) | (μm) | (μm) | (μm) | (μm) | (μm) | (μm) | (μm) | (μm) | (μm)
Left | 6004-2Z (https://www.skf.com/productcatalogue?language=en&system=metric&designation=6004-2Z) -20 | -7 | -10 | 0 | -11 | 0 | 9 | 34 | 7 | 12
Right | 6005-2Z (https://www.skf.com/productcatalogue?language=en&system=metric&designation=6005-2Z) -20 | -7 | -10 | 0 | -11 | 0 | 9 | 34 | 7 | 12

Consideration
For the tolerances calculation, the normal tolerance for the bearing bore and outer diameter is used.

## 3.10.2. Fits, Probable Interference (+) / Clearance (-)

| | | Shaft | | | | Housing
| Designation | | Probable
minimum | Middle | Probable
| | | | | | maximum | Probable
| | | | | | | minimum | | Middle | Probable maximum
(μm) | (μm) | (μm) | (μm) | (μm) | (μm)
Left | 6004-2Z (https://www.skf.com/productcatalogue?language=en&system=metric&designation=6004-2Z) | -24 | -16 | -7 | -53 | -39 | -25
Right | 6005-2Z (https://www.skf.com/productcatalogue?language=en&system=metric&designation=6004-2Z) | -24 | -16 | -7 | -53 | -39 | -25
SKF Bearing Select | 8

LIMITED WARRANTY : The SKF Bearing Select software tool of the SKF Company supports the calculation and selection of bearings.
| This software is provided 'as is' with out any warranty of any sort, implicitly as well as explicitly.
Please note that the obtained results can be affected by many external parameters and/or the quality of the assumptions taken into account. The results obtained using this software must be validated by the user who accepts the fact that the use of this software and the exploitation
| of the obtained results are under the user's entire and sole responsibility.

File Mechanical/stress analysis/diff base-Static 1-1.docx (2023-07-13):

# Loads and Fixtures

Fixture name | Fixture Image | Fixture Details

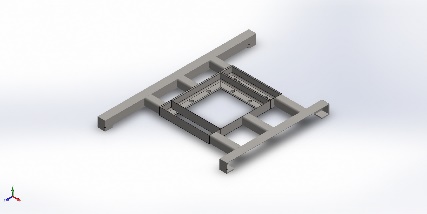
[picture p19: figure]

Fixed-1 | | Entities: 4 face(s) Type: Fixed Geometry

Resultant Forces

Components | X | Y | Z | Resultant
Reaction force(N) | 0.0109529 | 2,000.08 | 0.0403287 | 2,000.08
Reaction Moment(N.m) | 0 | 0 | 0 | 0

Load name | Load Image | Load Details

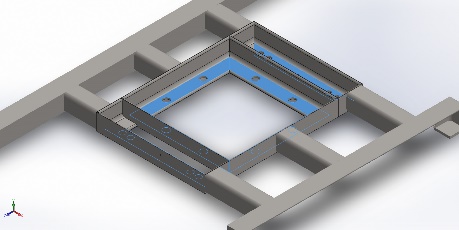
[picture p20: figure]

Force-1 | | Entities: 6 face(s) Type: Apply normal force Value: 2,000 N

# Resultant Forces

## Reaction forces

Selection set | Units | Sum X | Sum Y | Sum Z | Resultant
Entire Model | N | 0.0109529 | 2,000.08 | 0.0403287 | 2,000.08

## Reaction Moments

Selection set | Units | Sum X | Sum Y | Sum Z | Resultant
Entire Model | N.m | 0 | 0 | 0 | 0

## Free body forces

Selection set | Units | Sum X | Sum Y | Sum Z | Resultant
Entire Model | N | 1.51641 | -0.362137 | -0.756718 | 1.73299

## Free body moments

Selection set | Units | Sum X | Sum Y | Sum Z | Resultant
Entire Model | N.m | 0 | 0 | 0 | 1e-33

# Study Results

Name | Type | Min | Max
Stress1 | VON: von Mises Stress | 2.866e+03N/m^2 Node: 32377 | 1.902e+08N/m^2 Node: 20970

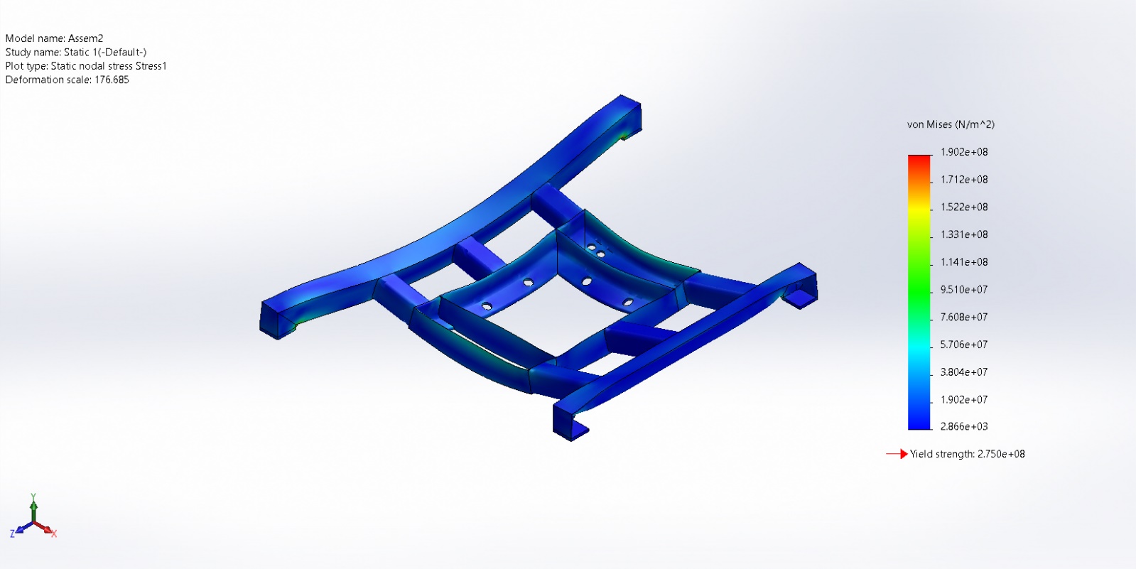
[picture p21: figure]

Assem2-Static 1-Stress-Stress1

Name | Type | Min | Max
Displacement1 | URES: Resultant Displacement | 0.000e+00mm Node: 25040 | 3.425e-01mm Node: 1209

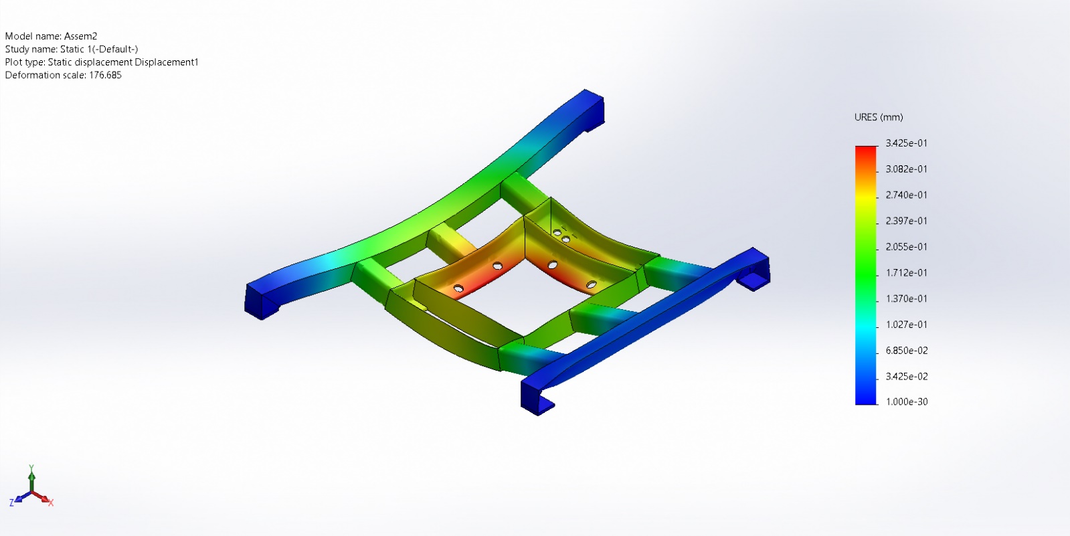
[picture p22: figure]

Assem2-Static 1-Displacement-Displacement1

Name | Type | Min | Max
Strain1 | ESTRN: Equivalent Strain | 2.256e-08 Element: 14857 | 6.594e-04 Element: 11234

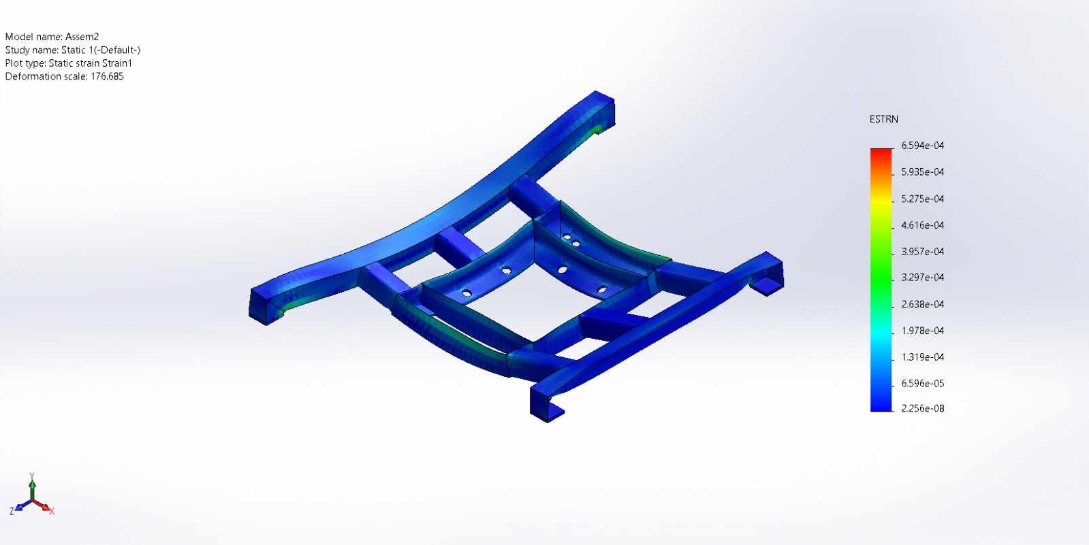
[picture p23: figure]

Assem2-Static 1-Strain-Strain1

Name | Type | Min | Max
Factor of Safety1 | Automatic | 1.446e+00 Node: 20970 | 9.595e+04 Node: 32377

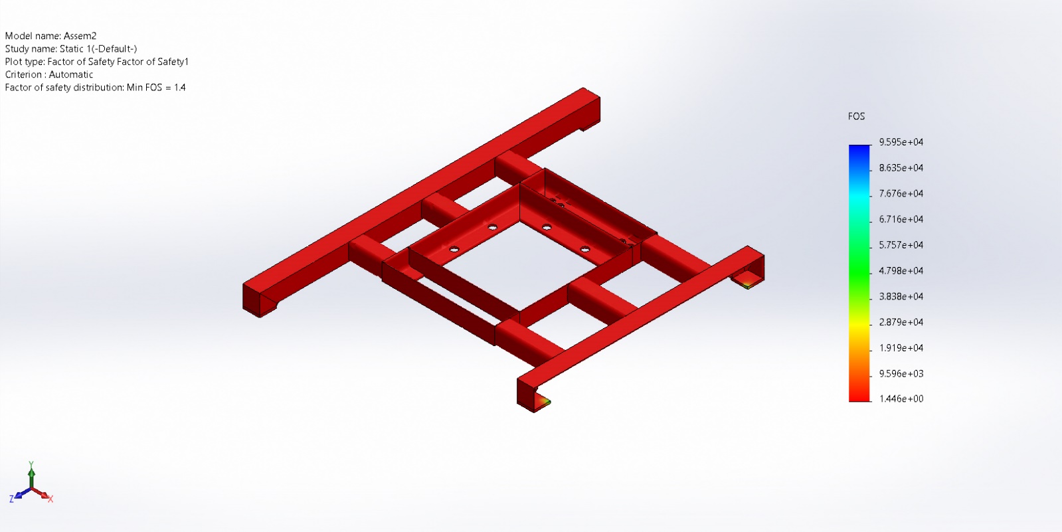
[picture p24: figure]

Assem2-Static 1-Factor of Safety-Factor of Safety1

Analyzed with SOLIDWORKS Simulation Simulation of Assem2 16

Analyzed with SOLIDWORKS Simulation Simulation of Assem2 1

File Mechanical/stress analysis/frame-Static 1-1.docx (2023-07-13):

# Loads and Fixtures

Fixture name | Fixture Image | Fixture Details

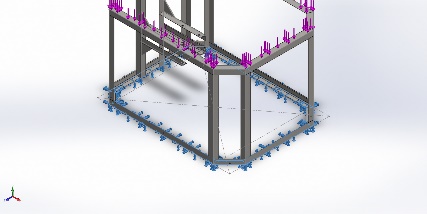
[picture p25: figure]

Fixed-1 | | Entities: 8 face(s) Type: Fixed Geometry

Resultant Forces

Components | X | Y | Z | Resultant
Reaction force(N) | -1.08798 | 2,997.97 | 0.161383 | 2,997.97
Reaction Moment(N.m) | 0 | 0 | 0 | 0

Load name | Load Image | Load Details

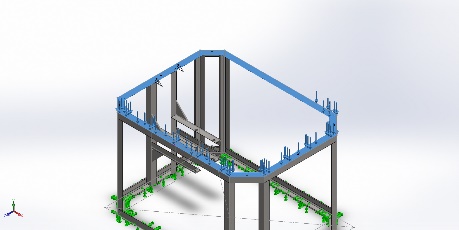
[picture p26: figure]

Force-1 | | Entities: 8 face(s) Type: Apply normal force Value: 3,000 N

# Contact Information

Contact | Contact Image | Contact Properties


Global Interaction | | Type: Bonded Components: 1 component(s) Options: Independent mesh

# Resultant Forces

## Reaction forces

Selection set | Units | Sum X | Sum Y | Sum Z | Resultant
Entire Model | N | -1.08798 | 2,997.97 | 0.161383 | 2,997.97

## Reaction Moments

Selection set | Units | Sum X | Sum Y | Sum Z | Resultant
Entire Model | N.m | 0 | 0 | 0 | 0

## Free body forces

Selection set | Units | Sum X | Sum Y | Sum Z | Resultant
Entire Model | N | 0.299263 | 0.956307 | 1.51447 | 1.81596

## Free body moments

Selection set | Units | Sum X | Sum Y | Sum Z | Resultant
Entire Model | N.m | 0 | 0 | 0 | 1e-33

# Study Results

Name | Type | Min | Max
Stress1 | VON: von Mises Stress | 3.270e-03N/m^2 Node: 274575 | 1.836e+08N/m^2 Node: 100404


Assem3-Static 1-Stress-Stress1

Name | Type | Min | Max
Displacement1 | URES: Resultant Displacement | 0.000e+00mm Node: 64624 | 8.732e-01mm Node: 496759


Assem3-Static 1-Displacement-Displacement1

Name | Type | Min | Max
Strain1 | ESTRN: Equivalent Strain | 2.272e-14 Element: 137346 | 4.686e-04 Element: 51406


Assem3-Static 1-Strain-Strain1

Name | Type | Min | Max
Factor of Safety1 | Automatic | 1.280e+00 Node: 100404 | 7.186e+10 Node: 274575


Assem3-Static 1-Factor of Safety-Factor of Safety1

Analyzed with SOLIDWORKS Simulation Simulation of Assem3 16

Analyzed with SOLIDWORKS Simulation Simulation of Assem3 1

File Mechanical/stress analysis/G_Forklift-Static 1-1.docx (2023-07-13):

# Loads and Fixtures

Fixture name | Fixture Image | Fixture Details


Fixed-1 | | Entities: 4 face(s) Type: Fixed Geometry

Resultant Forces

Components | X | Y | Z | Resultant
Reaction force(N) | -1,037.72 | -1,124.9 | 150.995 | 1,537.87
Reaction Moment(N.m) | 0 | 0 | 0 | 1e-33


Fixed-2 | | Entities: 2 face(s) Type: Fixed Geometry

Resultant Forces

Components | X | Y | Z | Resultant
Reaction force(N) | 1,037.72 | 3,124.89 | -150.995 | 3,296.15
Reaction Moment(N.m) | 0 | 0 | 0 | 1e-33

Load name | Load Image | Load Details


Force-1 | | Entities: 2 face(s) Type: Apply normal force Value: 2,000 N

# Resultant Forces

## Reaction forces

Selection set | Units | Sum X | Sum Y | Sum Z | Resultant
Entire Model | N | 0.00100279 | 2,000 | -0.000567675 | 2,000

## Reaction Moments

Selection set | Units | Sum X | Sum Y | Sum Z | Resultant
Entire Model | N.m | 0 | 0 | 0 | 1e-33

## Free body forces

Selection set | Units | Sum X | Sum Y | Sum Z | Resultant
Entire Model | N | 9.15557e-05 | 0.00306702 | 0.000122071 | 0.00307081

## Free body moments

Selection set | Units | Sum X | Sum Y | Sum Z | Resultant
Entire Model | N.m | -6.11526e-08 | 3.93861e-09 | -2.36145e-07 | 2.43966e-07

# Study Results

Name | Type | Min | Max
Stress1 | VON: von Mises Stress | 4.263e-10N/mm^2 (MPa) Node: 18234 | 1.767e+02N/mm^2 (MPa) Node: 4372


G_Forklift-Static 1-Stress-Stress1

Name | Type | Min | Max
Displacement1 | URES: Resultant Displacement | 0.000e+00mm Node: 9165 | 2.783e+00mm Node: 6660


G_Forklift-Static 1-Displacement-Displacement1

Name | Type | Min | Max
Strain1 | ESTRN: Equivalent Strain | 1.353e-15 Element: 8967 | 5.140e-04 Element: 4053


G_Forklift-Static 1-Strain-Strain1

Name | Type | Min | Max
Factor of Safety1 | Automatic | 1.557e+00 Node: 4372 | 6.450e+11 Node: 18234


G_Forklift-Static 1-Factor of Safety-Factor of Safety1

Analyzed with SOLIDWORKS Simulation Simulation of G_Forklift 16

Analyzed with SOLIDWORKS Simulation Simulation of G_Forklift 1

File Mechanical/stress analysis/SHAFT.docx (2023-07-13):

Shaft Component Generator (Version: 2023.1 (Build 271208000, 208))

1/31/2023

### Project Info (iProperties)

Summary

Title
Subject | - engma
Author
Manager
Company
Category
Keywords
Comments

Project

Part Number | diff shaft
Stock Number
Description
Revision Number
Project
Designer | engma
Engineer
Authority
Cost Center
Cost | $0.00
Date Created | 1/30/2023
Vendor
Catalog web link

Status

User Status
Design Status | 1
Last Saved By
Checked by
Engr Approved by
Date Eng Approved
Part Type name | Assembly
Mfg Approved by
Date Mfg Approved
Standard
Manufacturer
Standards Organization

### Calculation

Materia

Material Steel, nickel
Modulus of Elasticity E | | 205000 psi
Modulus of Rigidity | G _e | 80000 psi
Density | | 8280 lbmass/ft"3

Calculation Properties

Include | | I
Yes | Density | p I8280 lbmass/ft"3
- Yes | Shear Displacement Ratio | | 1.188ul
| Number of Divisions | I 1000.000 ul
| Mode of reduced stress | I HMH

Loads

Direction

55.18 deg

Deflection Angle

Location

Index

Supports

Index Type ,

LocationLI | | | Reaction Force | | _ | Yielding Type | y | Deflection _r] Size | I | Direction | Deflection Angle
| Y | El | Size I Direction | Axial Force


I

149.25

Fixed mm

-824.695

lbforce

180.00

deg

I

User

21.81 deg

I

Free 1244.5 mm 1397.473 lbforce

12.91 deg

180.00

deg

4.074

microin

microin

User1-4.074

2

180.00

deg

2.617

microin

-2.617

microin

824.695

lbforce

397.473

lbforce

Results

Length L

10.157 in

22.395 lbmass

26872.123 psi

1269.217 psi

0.000 psi

0.000 psi

26907.546 psi

4880233.108 microin

0.00 deg

Mass Mass

## Os

Maximal Bending Stress

Maximal Shear Stress

Maximal Torsional Stress

Maximal Tension Stress

Maximal Reduced Stress

Maximal Deflection

Angle of Twist

T5

-- T

aT

Ored

fmax

#### _cp_

Preview

Shear Force


Shear Force, YZ Plane


Shear Force, XZ Plane

0.5 -- - - - - - - - --+--

0+

+

+

-0.5 --

-f--

0 100

Length [mm]

200


Bending Moment


150

165.73

100

50

_4-

100

Length [mm]

200

Bending Moment, YZ Plane

150-+

+-

,,

100

50

I

0


E

b

-0.36B833

0 100

Length [mm]

200

Bending Moment, XZ Plane

1-

0.5 -- -------------+-------- --- -+--------

0-+

+-

+

-0.5 -- - - - - - - -

0 100

Length [mm]

200

Deflection Angle

60

56.2708


50

40

30

01

<])

20

10

--+----·--

0.0509858,

0+--r--c-- ----r--------,--r----,--------,-,-----i----,--_c-----r------r----r----r--------,--'!Cl'---,----,---,-----r ,--_ J

0 100 200

Length [mm]

Deflection Angle, YZ Plane

10

-i------------- 56.270I

I/

8

0

-10

-20

#### 01

<]) -30

-40

-50

-60

0

100

Length [mm]

200

Deflection Angle, XZ Plane

1

0.5 -- - - - - - - -

0+ + 1

01

<])

-0.5 --

-f--

-1+-----r--------,--r----,----,---c-- --r--------,-+-----,----,---c-- --r--------,-r----,----,-------l--r----r- -,-----r---

0 100

Length [mm]

200

Deflection

123958

100000- - +- +

'?

##### 2

..s

50000

100

Length [mm]

200

Deflection, YZ Plane

123958

100000

E

2u 50000

# E

0 +-------------;------""---=;:;-----S305.84 _;_;_;.=--=- =

100

Length [mm]

200

Deflection, XZ Plane

1-

0.5 -- ------------+-------- --- -+--------

Eo-+

2

..s

-0.5 --

+

+

0 100

Length [mm]

200

Bending Stress

200

185.277


150

'iii' 100

0..

# 6

50

0

0 100

Length [mm]

200


Bending Stress, YZ Plane

200

150

50-+-----------/·

0-;

o

-0.764686

t

t

#### 'iii'

0..

## 6

100

Length [mm]

200

Bending Stress, XZ Plane

Ill

0.5 -- - - - - - - -

0+

+

1

-0.5 --

-f--

6"-

0 100

Length [mm]

200

Shear Stress


g

B

B.75094 I

7

6

##### 5-t +

4+-----------I -+

L

3-+

2+--------------1

1

a- - - - - -

100

Length [mm]

Shear Stress, YZ Plane

I

L

i

r-s.5ss37

B.75094 I

5

-+-

-.--'-- -

.200

Ill

l

#### o

-5

0

100

Length [mm]

200

Shear Stress, XZ Plane

1

0.5 -- -----------+-------- --- -+--------

□-+

+

,

-0.5 -- - -

0 100

Length [mm]

200

Torsional Stress

Ill

0.5 -- - - - - - - -

0+

+

1

-0.5 --

-f--

6"-

0 100

Length [mm]

200

Tension Stress

1

0.5 -- -----------+-------- --- -+--------

0-+

+

,

-0.5 -- - -

0 100

Length [mm]

200

Reduced Stress


200

185.521

150

'iii' 100

6"-

50

0

0 100

Length [mm]

200

Ideal Diameter


E E

30

32.3204

20

10

+

0 100 200

Length [mm]

Summary of Messages

I1:08:16 PM Calculation: Calculated.I

file:///C:/Users/engma/AppData/Local/Temp/DA/SHAFT.html 7/8

1/31/23, 1:08 PM Shaft Component Generator

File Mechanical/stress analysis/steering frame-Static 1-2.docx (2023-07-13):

# Loads and Fixtures

Fixture name | Fixture Image | Fixture Details


Fixed-1 | | Entities: 8 face(s) Type: Fixed Geometry

Resultant Forces

Components | X | Y | Z | Resultant
Reaction force(N) | -7.31088e-05 | 2,500 | 4.18043e-05 | 2,500
Reaction Moment(N.m) | 0 | 0 | 0 | 0

Load name | Load Image | Load Details


Force-1 | | Entities: 4 face(s) Type: Apply normal force Value: 2,500 N

# Resultant Forces

## Reaction forces

Selection set | Units | Sum X | Sum Y | Sum Z | Resultant
Entire Model | N | -7.31088e-05 | 2,500 | 4.18043e-05 | 2,500

## Reaction Moments

Selection set | Units | Sum X | Sum Y | Sum Z | Resultant
Entire Model | N.m | 0 | 0 | 0 | 0

## Free body forces

Selection set | Units | Sum X | Sum Y | Sum Z | Resultant
Entire Model | N | -0.0015284 | -0.00786662 | -0.00386611 | 0.00889756

## Free body moments

Selection set | Units | Sum X | Sum Y | Sum Z | Resultant
Entire Model | N.m | 0 | 0 | 0 | 1e-33

# Study Results

Name | Type | Min | Max
Stress1 | VON: von Mises Stress | 7.493e-07N/mm^2 (MPa) Node: 12125 | 1.339e+02N/mm^2 (MPa) Node: 8412


Assem1-Static 1-Stress-Stress1

Name | Type | Min | Max
Displacement1 | URES: Resultant Displacement | 0.000e+00mm Node: 5528 | 1.057e-01mm Node: 25233


Assem1-Static 1-Displacement-Displacement1

Name | Type | Min | Max
Strain1 | ESTRN: Equivalent Strain | 1.176e-10 Element: 7064 | 4.720e-04 Element: 11774


Assem1-Static 1-Strain-Strain1

Name | Type | Min | Max
Factor of Safety1 | Automatic | 1.756e+00 Node: 8412 | 3.136e+08 Node: 12125


Assem1-Static 1-Factor of Safety-Factor of Safety1

Name | Type
Displacement1{1} | Deformed shape


Assem1-Static 1-Displacement-Displacement1{1}

Analyzed with SOLIDWORKS Simulation Simulation of Assem1 16

Analyzed with SOLIDWORKS Simulation Simulation of Assem1 1

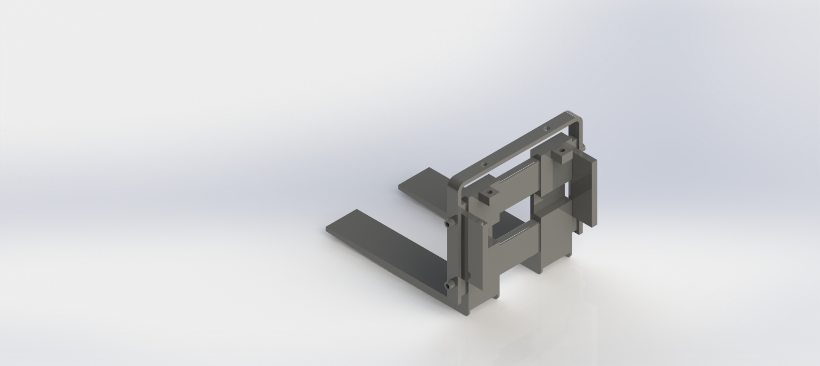
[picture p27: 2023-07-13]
Mechanical/photos/fork.JPG

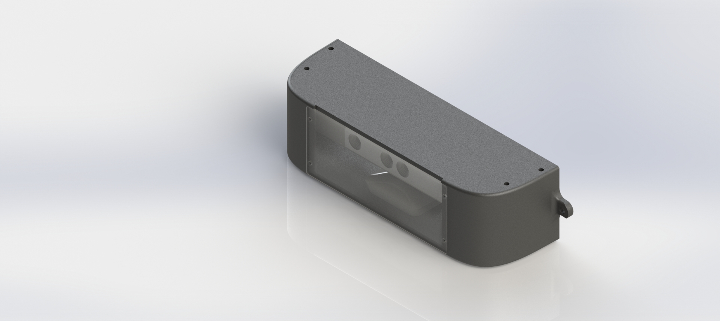
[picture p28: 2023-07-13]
Mechanical/photos/k.JPG

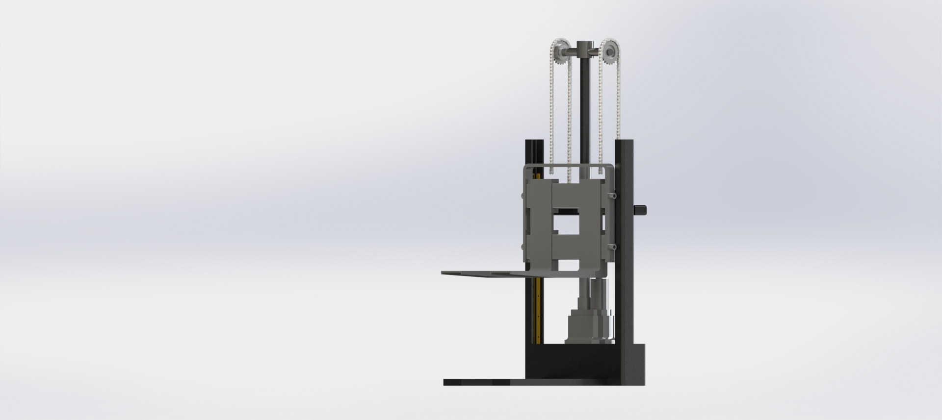
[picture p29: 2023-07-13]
Mechanical/photos/forklift.JPG

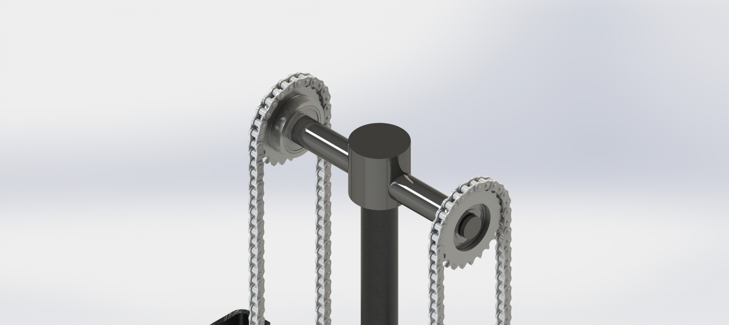
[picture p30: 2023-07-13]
Mechanical/photos/ss.JPG

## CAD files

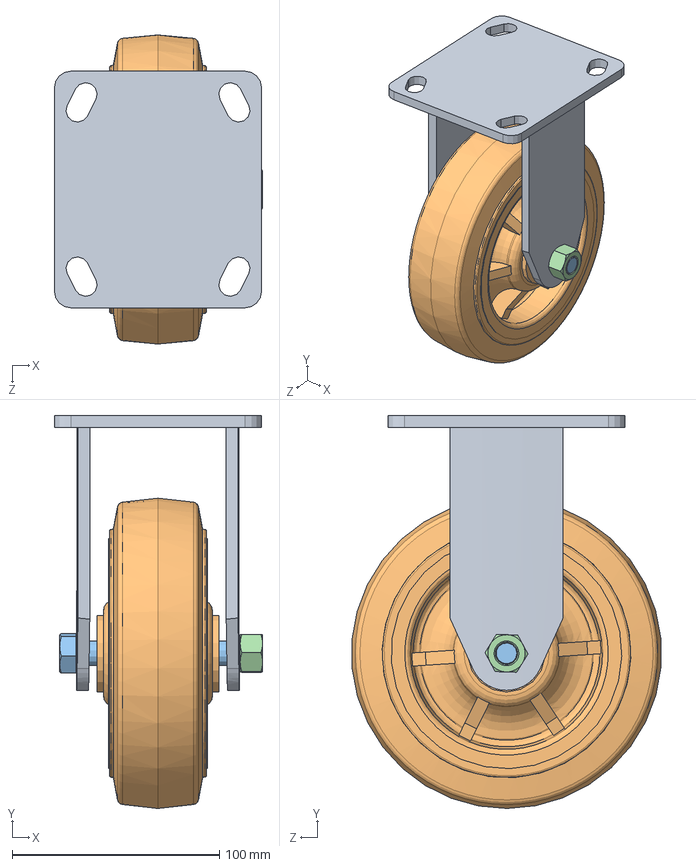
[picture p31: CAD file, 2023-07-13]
Mechanical/EXTRA/6-inch-rigid-caster-from-northern-tools-1.snapshot.6/6inchRigidCasterNorthernTools.SLDASM
100.5 x 189.8 x 149.3 mm
RigidCasterFrameNorthernTools
6inCasterWheelNorthernTools
hex bolt_am
hex nut style 1_am

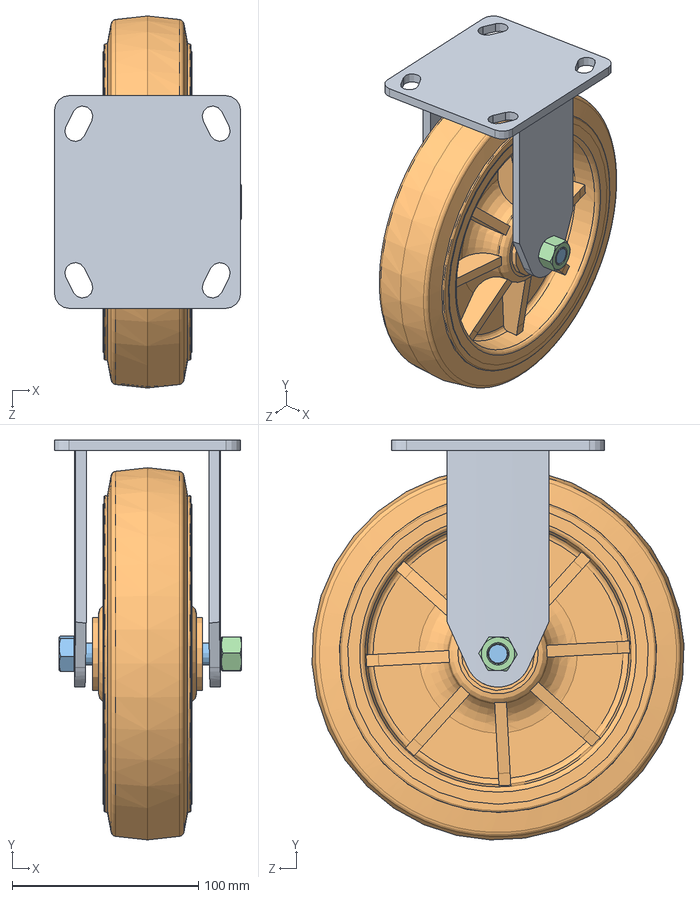
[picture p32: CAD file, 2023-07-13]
Mechanical/EXTRA/6-inch-rigid-caster-from-northern-tools-1.snapshot.6/6inchRigidCasterNorthernTools/6inchRigidCasterNorthernTools.SLDASM
100.5 x 214.9 x 199.9 mm
RigidCasterFrameNorthernTools
8inWheel
hex bolt_am
hex nut style 1_am

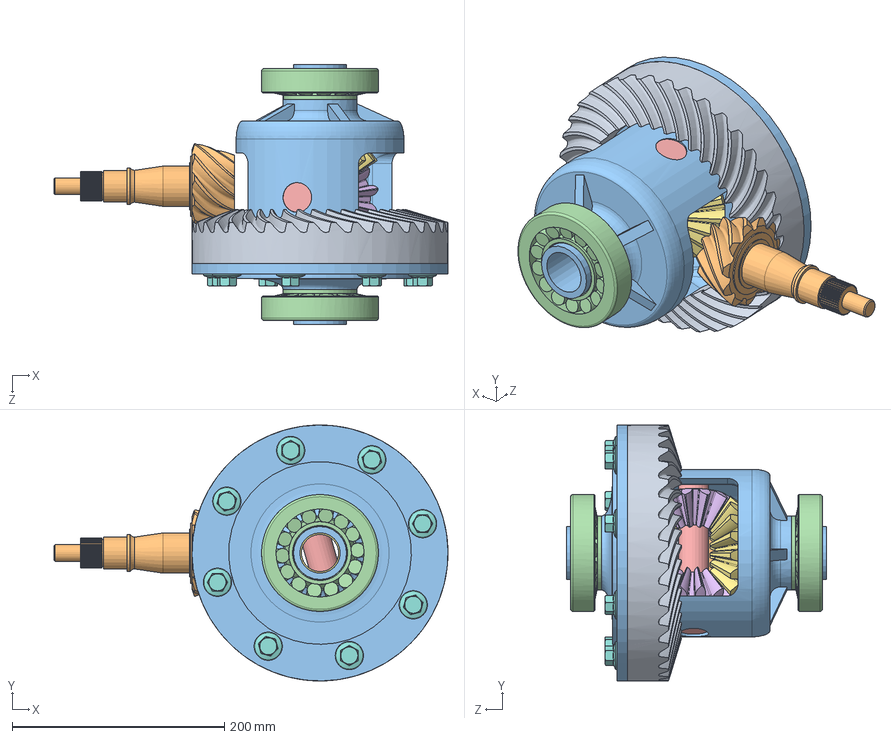
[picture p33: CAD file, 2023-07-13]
Mechanical/EXTRA/differential-22.snapshot.3/Assembly.SLDASM
371.0 x 241.0 x 244.5 mm
lautaspyörä
pienipyörä_1
Runko
taper roller bearing_skf x 2
Pinioniakseli
straight bevel pinion_iso x 2
straight bevel gear_iso x 2
hex flange bolt_din x 8

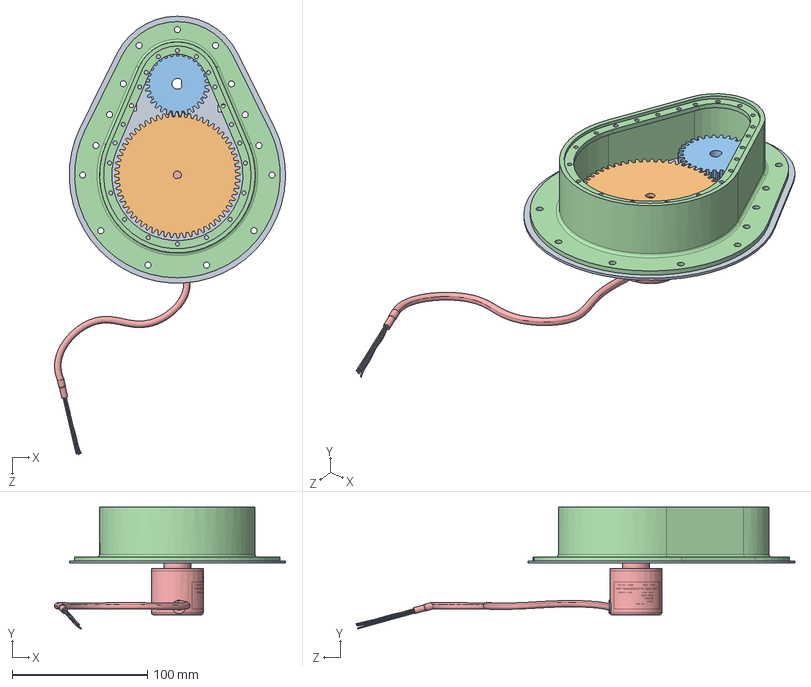
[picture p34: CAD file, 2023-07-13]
Mechanical/Graduation solidworks/additional/steering encoder gearbox/gearbox parts/gearbox ass.SLDASM
170.8 x 90.2 x 324.4 mm
motor plate
encoder_gear
motor_gear
motor cover
Encoder Rotary

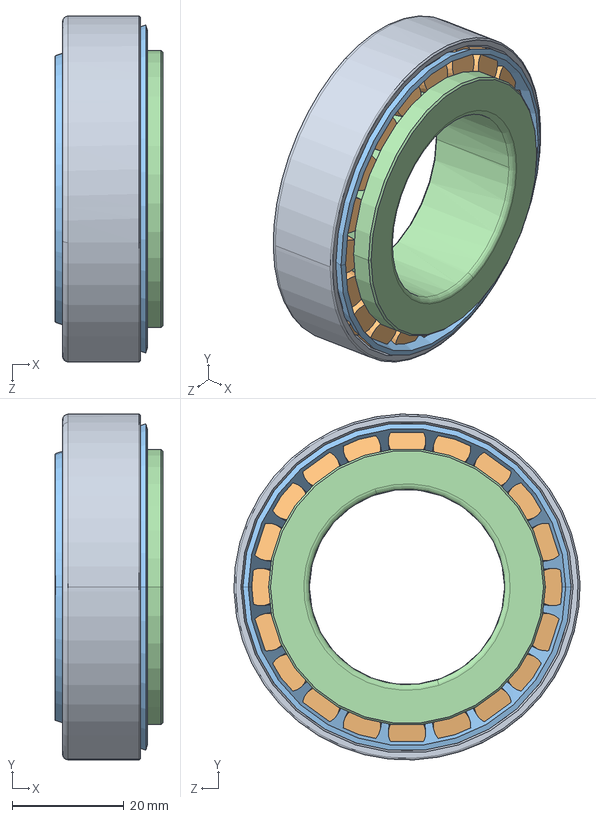
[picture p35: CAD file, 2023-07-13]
Mechanical/Graduation solidworks/differential/SKF_CAD_MODEL_SKF_32007 X/SOLIDWORKS/SKF_32007_X.sldasm
19.3 x 62.0 x 62.0 mm
SKF_32007_X_3
SKF_32007_X_5 x 20
SKF_32007_X_26
SKF_32007_X_28

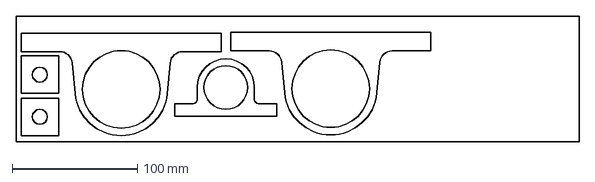
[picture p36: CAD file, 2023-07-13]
Mechanical/Drawings/CNC DXF/Total 15mm thick.dxf
450.0 x 100.0 mm

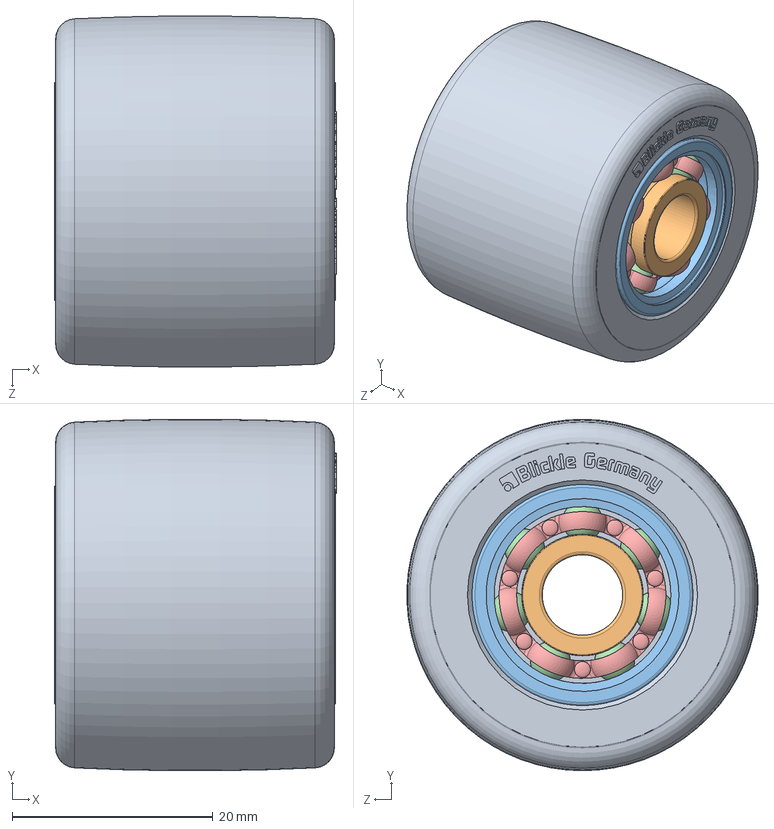
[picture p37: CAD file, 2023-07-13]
Mechanical/EXTRA/blickle-wheel-gspo-35-8k-g15-1.snapshot.4/GSPO 35-8K G15 Blikle Wheel/GSPO 35-8K G15 Blikle Wheel.SLDASM
28.1 x 35.0 x 34.9 mm
GSPO 35-8K G15 Blikle Roller
608 Inner Race^608 x 2
608 Outer Race^608 x 2
608 Ball^608 x 14
Ball retainer rings^608 x 2

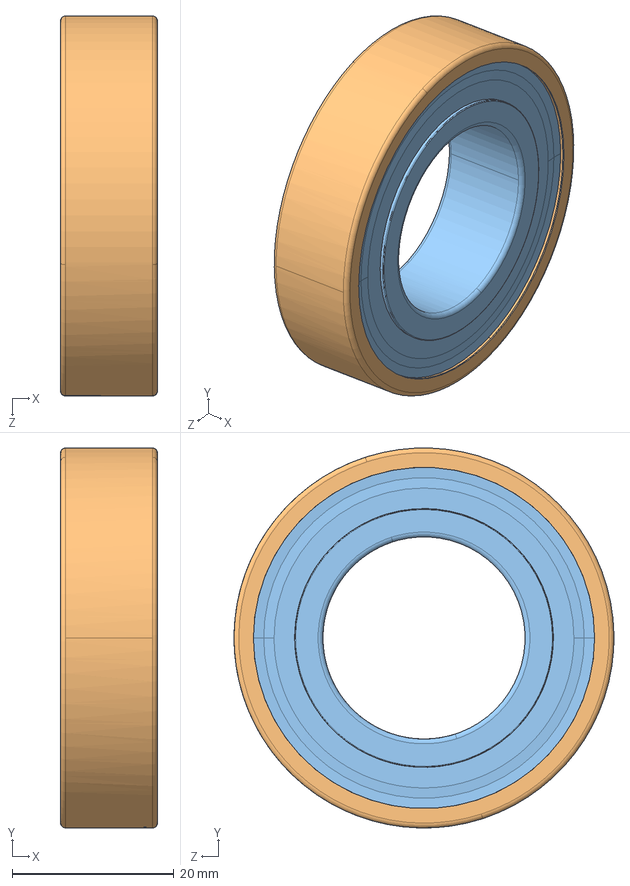
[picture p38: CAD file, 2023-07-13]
Mechanical/Graduation solidworks/differential/SKF_CAD_MODEL_SKF_6005-2Z/SOLIDWORKS/SKF_6005_2Z.sldasm
12.0 x 47.0 x 47.0 mm
SKF_6005_2Z_14 x 10
SKF_6005_2Z_25
SKF_6005_2Z_27

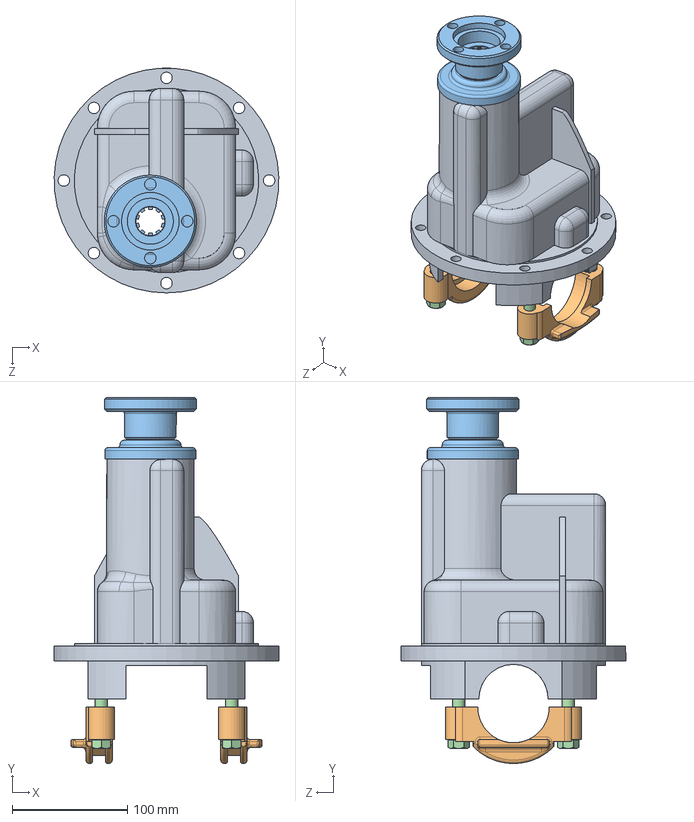
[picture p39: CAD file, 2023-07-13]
Mechanical/EXTRA/differential-housing-1.snapshot.5 (1)/Differential Housing.SLDASM
194.9 x 317.5 x 195.0 mm
Housing
Bearing Holder1 x 2
new coupler
BOLT x 4

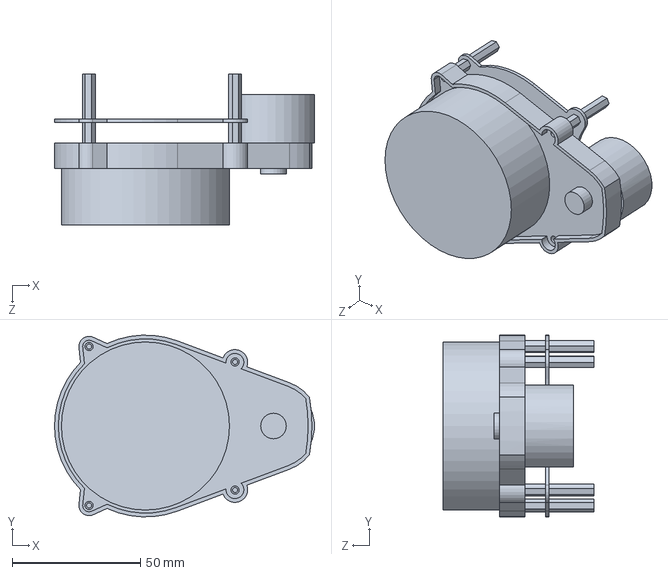
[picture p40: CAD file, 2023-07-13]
Mechanical/Graduation solidworks/additional/3d for lidar/assem lidar.SLDASM
101.5 x 70.9 x 59.0 mm

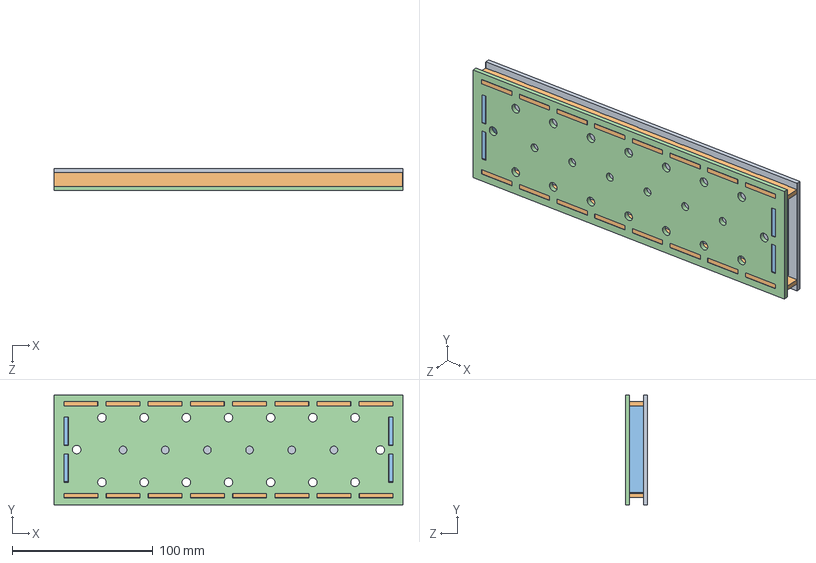
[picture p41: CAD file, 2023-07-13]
Mechanical/Graduation solidworks/additional/3d for torch/side_torch_assem.SLDASM
248.2 x 78.0 x 16.0 mm
side_torch_شفاف
side_torch_long_side x 2
side_torch_short_side x 2
side_torch_شفاف مشش

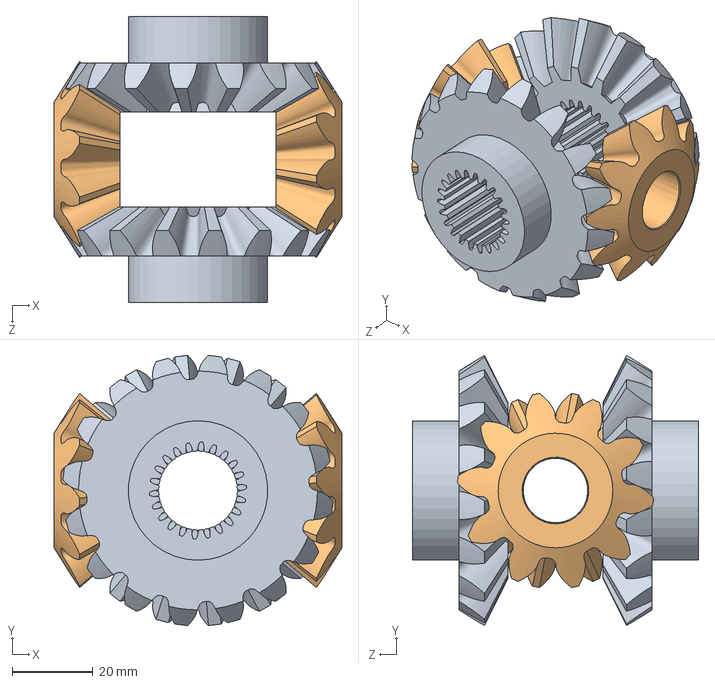
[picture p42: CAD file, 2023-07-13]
Mechanical/Graduation solidworks/differential/Assemblygears2.SLDASM
71.3 x 66.9 x 70.8 mm
Bevel01_2 x 2
Bevel02_2 x 2

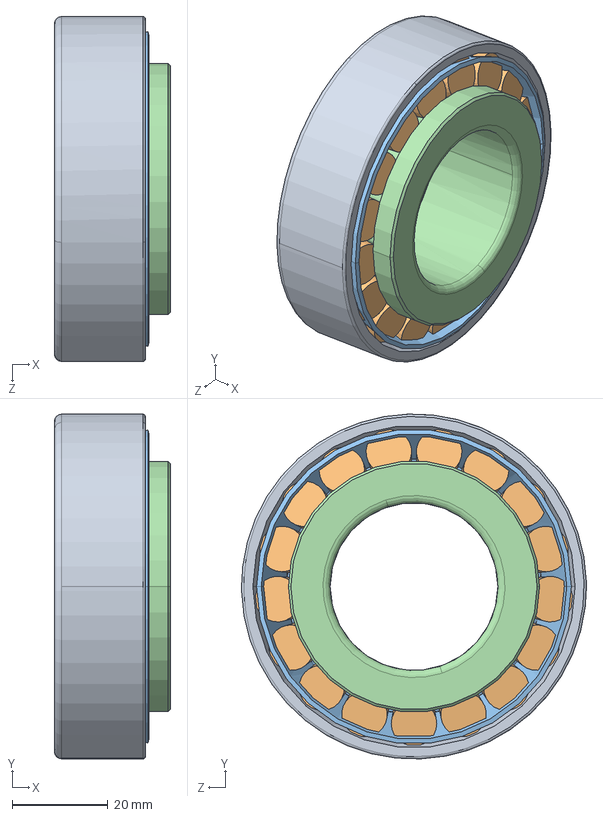
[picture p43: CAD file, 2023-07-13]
Mechanical/Graduation solidworks/differential/SKF_CAD_MODEL_SKF_32207/SOLIDWORKS/SKF_32207.sldasm
24.2 x 72.0 x 72.0 mm
SKF_32207_3
SKF_32207_5 x 17
SKF_32207_23
SKF_32207_25

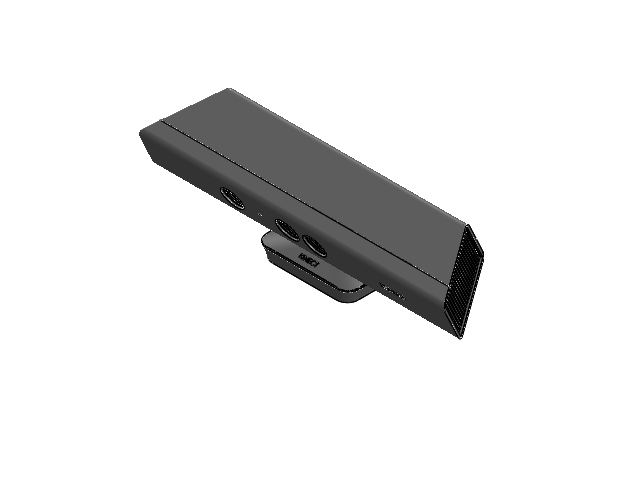
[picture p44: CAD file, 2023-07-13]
Mechanical/Graduation solidworks/additional/kinect/final kinect.SLDASM
lower part
kinect upper part

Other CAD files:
Mechanical/Graduation solidworks/G_Solidwork/SKF_CAD_MODEL_SKF_6005-2Z/SOLIDWORKS/SKF_6005_2Z.sldasm
Mechanical/Graduation solidworks/differential/SKF_CAD_MODEL_SKF_322_28 B/SOLIDWORKS/SKF_322_28 B.sldasm
Mechanical/Graduation solidworks/G_Solidwork/kinect-1/final kinect.SLDASM
Mechanical/Graduation solidworks/differential/SKF_CAD_MODEL_SKF_62_28/SOLIDWORKS/SKF_62_28.sldasm
Mechanical/ASS Templete.SLDDRW
Mechanical/Drawings/CNC DXF/Flat pattern - cover of wheel 2.DXF
Mechanical/Drawings/CNC DXF/Flat pattern - cover of wheel.DXF
Mechanical/Drawings/CNC DXF/Flat pattern - middle front sheet metal.DXF
Mechanical/Drawings/CNC DXF/Flat pattern - sheet metal front Side mirror.DXF
Mechanical/Drawings/CNC DXF/Flat pattern - sheet metal front Side.DXF
Mechanical/Drawings/CNC DXF/Flat pattern - sheet metal of back split.DXF
Mechanical/Drawings/CNC DXF/Flat pattern - sheet metal of back.DXF
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

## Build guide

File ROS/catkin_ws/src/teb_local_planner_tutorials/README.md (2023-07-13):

# teb_local_planner_tutorials
This package contains supplementary material and examples for [teb_local_planner](http://wiki.ros.org/teb_local_planner) tutorials.

The tutorials package mainly contains fully working robot navigation examples in combination with the teb_local_planner.
Currently it provides a differential drive and a carlike robot simulation setup.
In order to depend on as few dependencies as possible, the simulations are performed with [stage_ros](http://wiki.ros.org/stage_ros)
and without any URDF models. However, they are easily extendable and integrable (e.g. Gazebo, URDF models, voxel costmaps, robot hardware nodes, ...).

Refer to the [teb_local_planner](http://wiki.ros.org/teb_local_planner) ROS wiki page for more information.

**Dependencies:**

 * *navigation stack* and *teb_local_planner* package
 * *stage*: `sudo apt-get install ros-melodic-stage-ros`

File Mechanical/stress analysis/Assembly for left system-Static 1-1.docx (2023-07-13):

# Loads and Fixtures

Fixture name | Fixture Image | Fixture Details

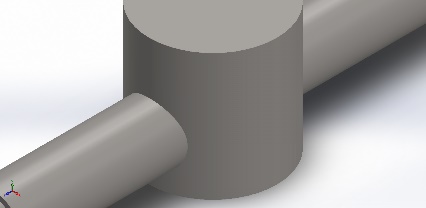
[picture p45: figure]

Fixed-1 | | Entities: 2 face(s) Type: Fixed Geometry

Resultant Forces

Components | X | Y | Z | Resultant
Reaction force(N) | 0.0071032 | 2,499.97 | 0.0577974 | 2,499.97
Reaction Moment(N.m) | 0 | 0 | 0 | 0

Load name | Load Image | Load Details

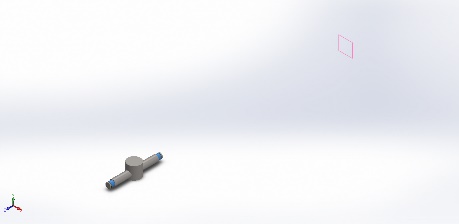
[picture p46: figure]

Force-1 | | Entities: 2 face(s), 1 plane(s) Reference: Front Plane Type: Apply force Values: ---, -2,500, --- N

# Resultant Forces

## Reaction forces :

Selection set | Units | Sum X | Sum Y | Sum Z | Resultant
Entire Model | N | 0.0071032 | 2,499.97 | 0.0577974 | 2,499.97

## Reaction Moments :

Selection set | Units | Sum X | Sum Y | Sum Z | Resultant
Entire Model | N.m | 0 | 0 | 0 | 0

## Free body forces :

Selection set | Units | Sum X | Sum Y | Sum Z | Resultant
Entire Model | N | -0.0540897 | -0.184324 | 0.128691 | 0.231219

## Free body moments :

Selection set | Units | Sum X | Sum Y | Sum Z | Resultant
Entire Model | N.m | 0 | 0 | 0 | 1e-33

# Study Results

Name | Type | Min | Max
Stress1 | VON: von Mises Stress | 8.708e-03N/mm^2 (MPa) Node: 14985 | 1.086e+02N/mm^2 (MPa) Node: 1

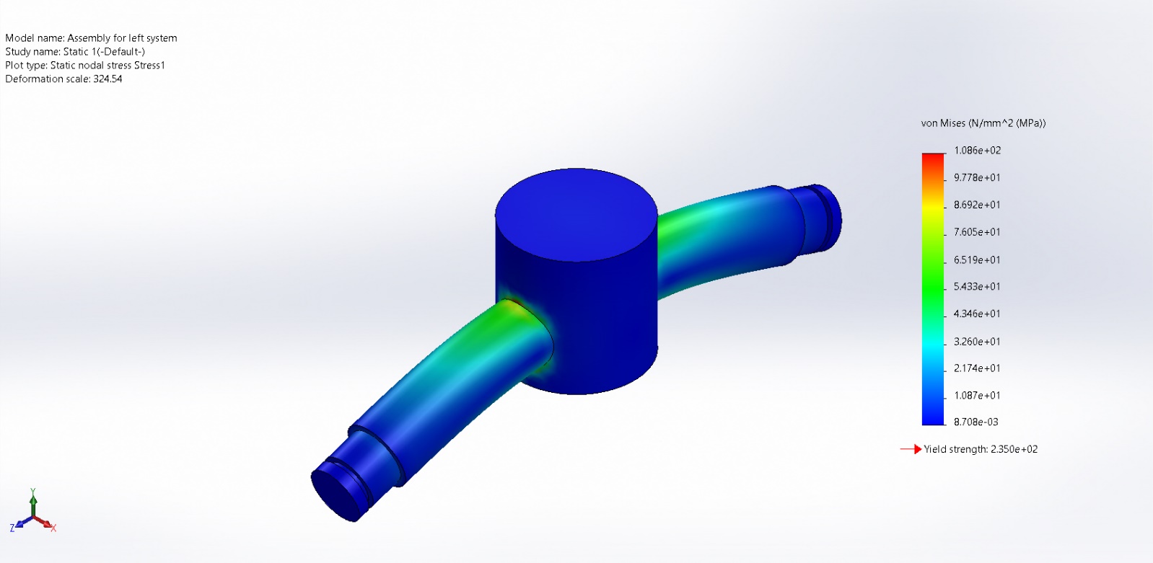
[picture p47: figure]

Assembly for left system-Static 1-Stress-Stress1

Name | Type | Min | Max
Displacement1 | URES: Resultant Displacement | 0.000e+00mm Node: 12 | 6.550e-02mm Node: 23336

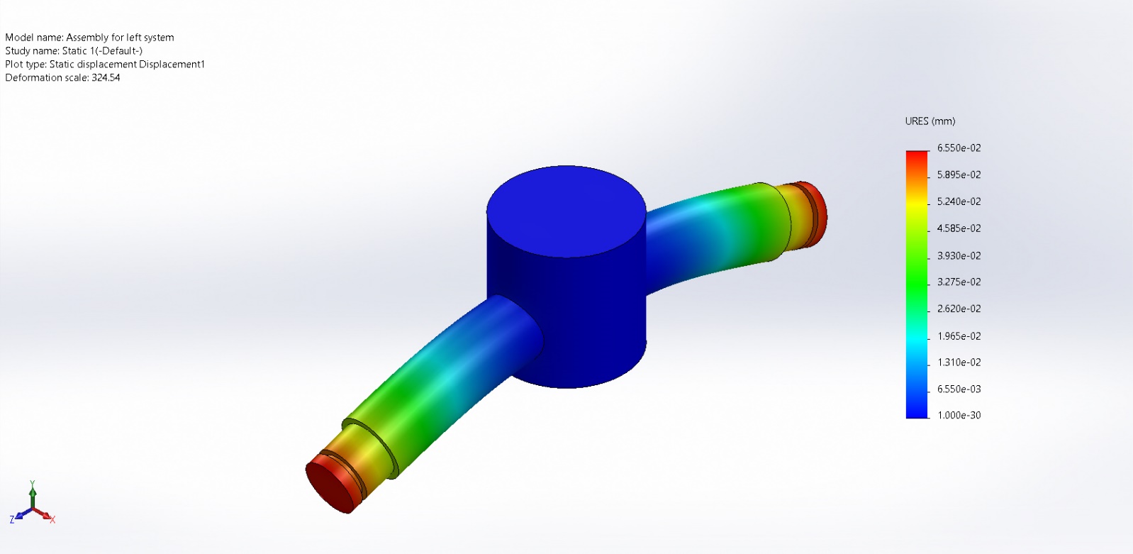
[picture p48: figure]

Assembly for left system-Static 1-Displacement-Displacement1

Name | Type | Min | Max
Strain1 | ESTRN: Equivalent Strain | 1.096e-07 Element: 17392 | 2.783e-04 Element: 14864

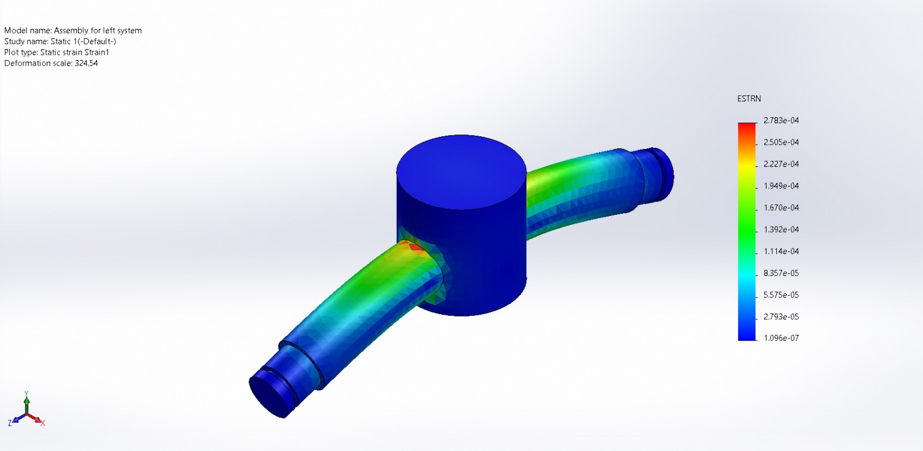
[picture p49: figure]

Assembly for left system-Static 1-Strain-Strain1

Name | Type | Min | Max
Factor of Safety1 | Automatic | 2.163e+00 Node: 1 | 2.699e+04 Node: 14985

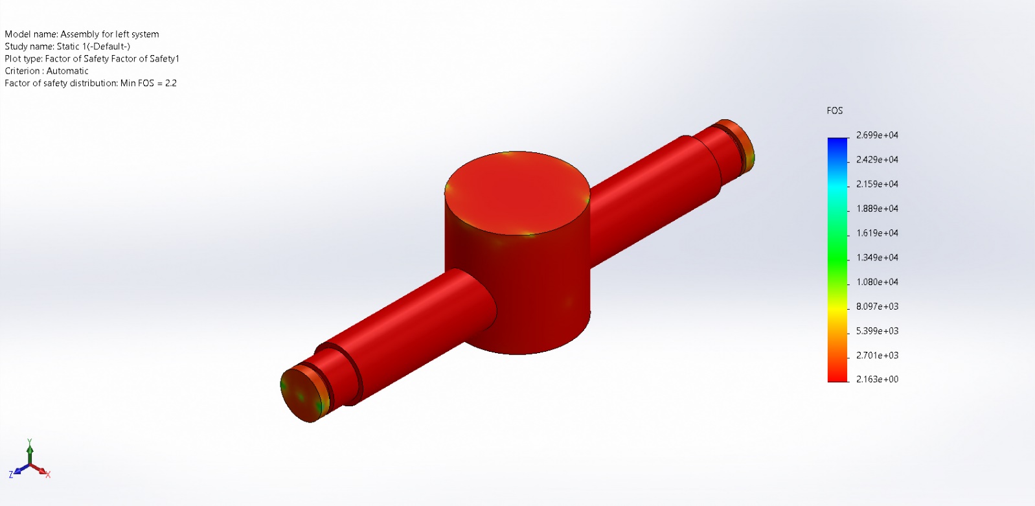
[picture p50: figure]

Assembly for left system-Static 1-Factor of Safety-Factor of Safety1

Analyzed with SOLIDWORKS Simulation Simulation of Assembly for left system 16

Analyzed with SOLIDWORKS Simulation Simulation of Assembly for left system 1

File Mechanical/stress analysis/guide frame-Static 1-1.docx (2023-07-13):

# Loads and Fixtures

Fixture name | Fixture Image | Fixture Details

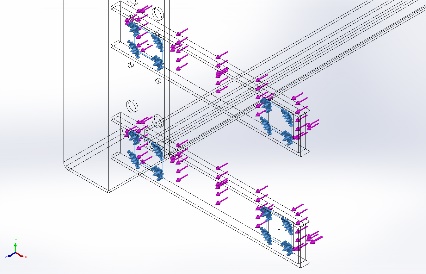
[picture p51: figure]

Fixed-1 | | Entities: 4 face(s) Type: Fixed Geometry

Resultant Forces

Components | X | Y | Z | Resultant
Reaction force(N) | -6.10352e-05 | -1.81198e-05 | -8,000 | 8,000
Reaction Moment(N.m) | 0 | 0 | 0 | 0

Load name | Load Image | Load Details

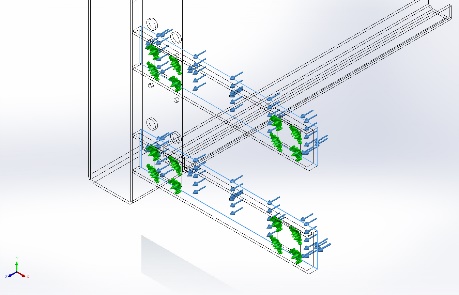
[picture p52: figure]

Force-1 | | Entities: 2 face(s) Type: Apply normal force Value: 4,000 N

# Resultant Forces :

## Reaction forces :

Selection set | Units | Sum X | Sum Y | Sum Z | Resultant
Entire Model | N | -6.10352e-05 | -1.81198e-05 | -8,000 | 8,000

## Reaction Moments :

Selection set | Units | Sum X | Sum Y | Sum Z | Resultant
Entire Model | N.m | 0 | 0 | 0 | 0

## Free body forces :

Selection set | Units | Sum X | Sum Y | Sum Z | Resultant
Entire Model | N | 5.26852e-05 | 9.29e-06 | 0.00831756 | 0.00831773

## Free body moments :

Selection set | Units | Sum X | Sum Y | Sum Z | Resultant
Entire Model | N.m | 0 | 0 | 0 | 1e-33

# Study Results

Name | Type | Min | Max
Stress1 | VON: von Mises Stress | 1.780e-01N/m^2 Node: 58734 | 4.219e+07N/m^2 Node: 20603

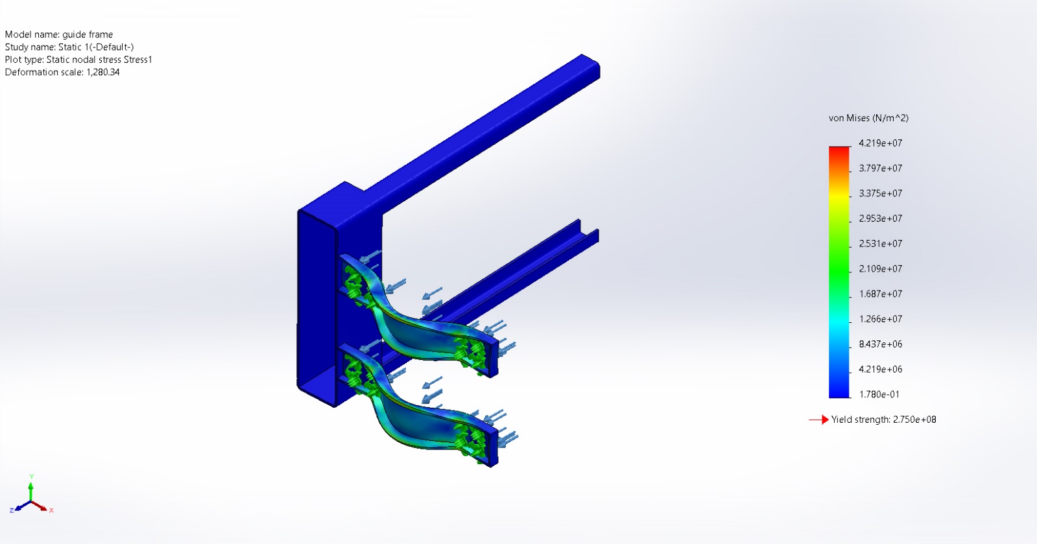
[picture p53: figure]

guide frame-Static 1-Stress-Stress1

Name | Type | Min | Max
Displacement1 | URES: Resultant Displacement | 0.000e+00mm Node: 19797 | 5.647e-02mm Node: 20862

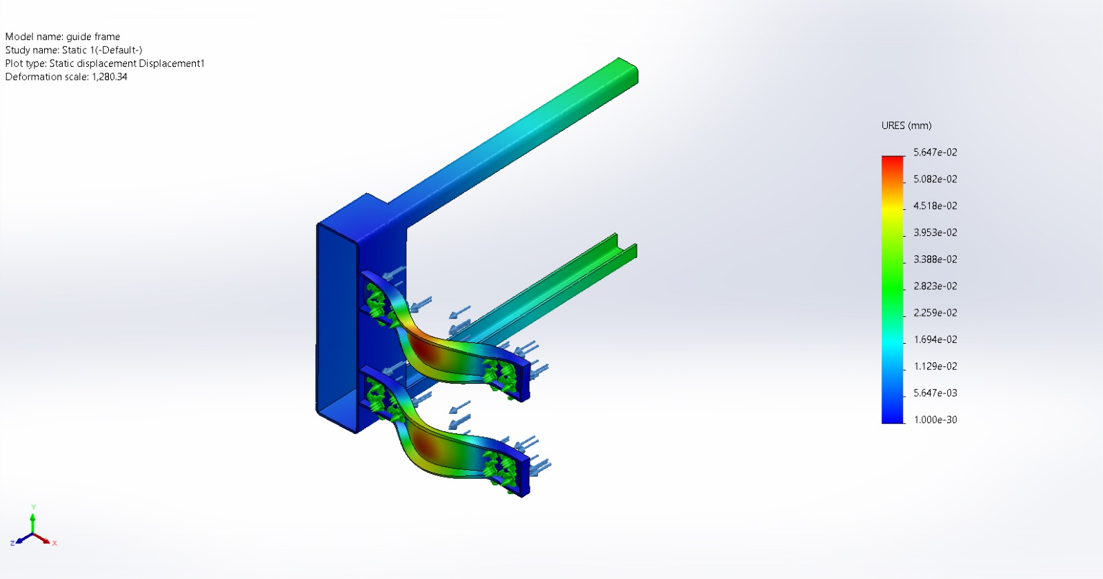
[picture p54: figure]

guide frame-Static 1-Displacement-Displacement1

Name | Type | Min | Max
Strain1 | ESTRN: Equivalent Strain | 3.784e-13 Element: 17928 | 1.046e-04 Element: 10699

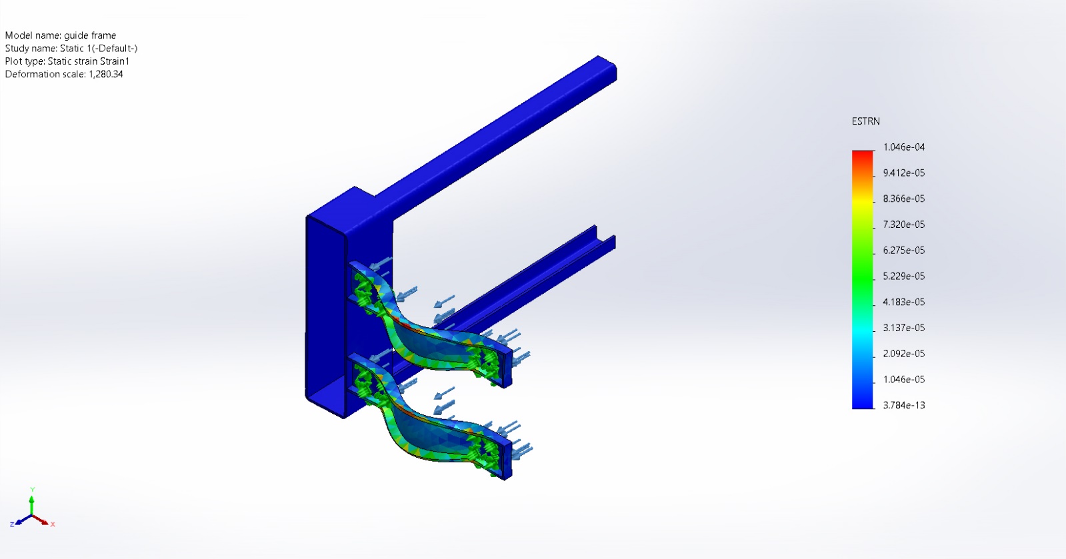
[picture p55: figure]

guide frame-Static 1-Strain-Strain1

Name | Type
Displacement1{1} | Deformed shape

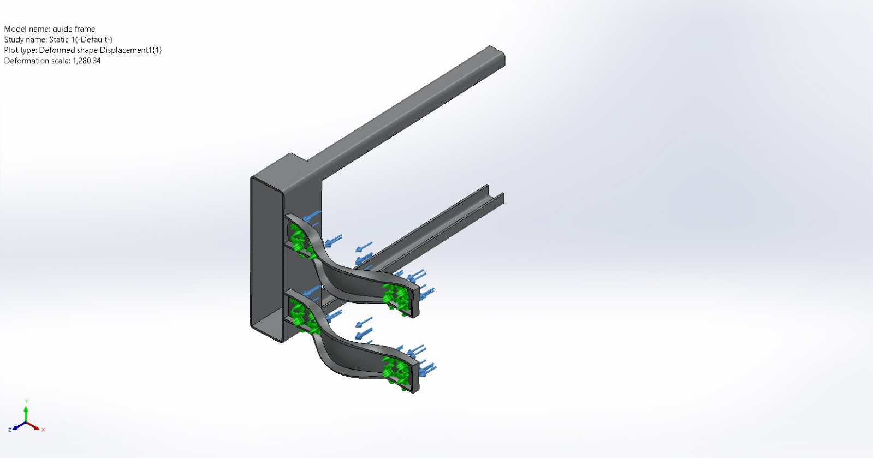
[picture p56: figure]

guide frame-Static 1-Displacement-Displacement1{1}

# Conclusion

Analyzed with SOLIDWORKS Simulation Simulation of guide frame 16

Analyzed with SOLIDWORKS Simulation Simulation of guide frame 1

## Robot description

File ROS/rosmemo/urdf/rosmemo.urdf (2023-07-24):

<?xml version="1.0" encoding="utf-8"?>
<!-- This URDF was automatically created by SolidWorks to URDF Exporter! Originally created by Stephen Brawner (brawner@gmail.com) 
     Commit Version: 1.6.0-4-g7f85cfe  Build Version: 1.6.7995.38578
     For more information, please see http://wiki.ros.org/sw_urdf_exporter -->
<robot name="rosmemo">
  <link name="base_link">
    <inertial>
      <origin xyz="-0.00018563 0.07284 0.26435" rpy="0 0 0" />
      <mass value="11.579" />
      <inertia ixx="0.32726" ixy="-0.00099205" ixz="-0.014545" iyy="0.2471" iyz="-0.021278" izz="0.25547" />
    </inertial>
    <visual>
      <origin xyz="0 0 0" rpy="0 0 0" />
      <geometry>
        <mesh filename="package://rosmemo/meshes/base_link.STL" />
      </geometry>
      <material name="">
        <color rgba="0.79216 0.81961 0.93333 1" />
      </material>
    </visual>
    <collision>
      <origin xyz="0 0 0" rpy="0 0 0" />
      <geometry>
        <mesh filename="package://rosmemo/meshes/base_link.STL" />
      </geometry>
    </collision>
  </link>
  <link name="right_wheel">
    <inertial>
      <origin xyz="0.2145 6.5149E-16 0.04" rpy="0 0 0" />
      <mass value="1.5105" />
      <inertia ixx="0.013449" ixy="1.9998E-17" ixz="-4.2352E-19" iyy="0.0069542" iyz="-1.89E-18" izz="0.0069542" />
    </inertial>
    <visual>
      <origin xyz="0 0 0" rpy="0 0 0" />
      <geometry>
        <mesh filename="package://rosmemo/meshes/right_wheel.STL" />
      </geometry>
      <material name="">
        <color rgba="0.79216 0.81961 0.93333 1" />
      </material>
    </visual>
    <collision>
      <origin xyz="0 0 0" rpy="0 0 0" />
      <geometry>
        <mesh filename="package://rosmemo/meshes/right_wheel.STL" />
      </geometry>
    </collision>
  </link>
  <joint name="rightaxisdiff" type="revolute">
    <origin xyz="0 0 0" rpy="0 0 0" />
    <parent link="base_link" />
    <child link="right_wheel" />
    <axis xyz="-1 0 0" />
    <limit lower="0" upper="0" effort="30" velocity="3" />
  </joint>
  <link name="left_wheel">
    <inertial>
      <origin xyz="-0.214500000000001 -6.40411416370602E-16 0.0400000000000001" rpy="0 0 0" />
      <mass value="1.51052382245882" />
      <inertia ixx="0.0134488232861342" ixy="1.91905902112302E-17" ixz="-4.2351647362715E-19" iyy="0.00695418595705467" iyz="1.15950042364621E-18" izz="0.00695418595705467" />
    </inertial>
    <visual>
      <origin xyz="0 0 0" rpy="0 0 0" />
      <geometry>
        <mesh filename="package://rosmemo/meshes/left_wheel.STL" />
      </geometry>
      <material name="">
        <color rgba="0.792156862745098 0.819607843137255 0.933333333333333 1" />
      </material>
    </visual>
    <collision>
      <origin xyz="0 0 0" rpy="0 0 0" />
      <geometry>
        <mesh filename="package://rosmemo/meshes/left_wheel.STL" />
      </geometry>
    </collision>
  </link>
  <joint name="leftaxisdiff" type="revolute">
    <origin xyz="0 0 0" rpy="0 0 0" />
    <parent link="base_link" />
    <child link="left_wheel" />
    <axis xyz="1 0 0" />
    <limit lower="0" upper="0" effort="30" velocity="3" />
  </joint>
  <link name="steering_wheel">
    <inertial>
      <origin xyz="2.4363826477525E-05 -0.357987244898522 0.0149999988901958" rpy="0 0 0" />
      <mass value="0.951413868841419" />
      <inertia ixx="0.00478609758628271" ixy="0.00103716590931801" ixz="2.39970307380687E-12" iyy="0.00334802981308699" iyz="-1.22299043941559E-11" izz="0.00280503246112036" />
    </inertial>
    <visual>
      <origin xyz="0 0 0" rpy="0 0 0" />
      <geometry>
        <mesh filename="package://rosmemo/meshes/steering_wheel.STL" />
      </geometry>
      <material name="">
        <color rgba="0.792156862745098 0.819607843137255 0.933333333333333 1" />
      </material>
    </visual>
    <collision>
      <origin xyz="0 0 0" rpy="0 0 0" />
      <geometry>
        <mesh filename="package://rosmemo/meshes/steering_wheel.STL" />
      </geometry>
    </collision>
  </link>
  <joint name="steeringwheelaxis" type="revolute">
    <origin xyz="0 0 0" rpy="0 0 0" />
    <parent link="base_link" />
    <child link="steering_wheel" />
    <axis xyz="-0.88593 -0.46382 0" />
    <limit lower="0" upper="0" effort="30" velocity="3" />
  </joint>
  <link name="steering_angle">
    <inertial>
      <origin xyz="0 0 0" rpy="0 0 0" />
      <mass value="0.951413868841419" />
      <inertia ixx="0.00478609758628271" ixy="0.00103716590931801" ixz="2.39970307380687E-12" iyy="0.00334802981308699" iyz="-1.22299043941559E-11" izz="0.00280503246112036" />
    </inertial>
    <visual>
      <origin xyz="0 0 0" rpy="0 0 0" />
      <geometry>
        <mesh filename="package://rosmemo/meshes/steering_angle.STL" />
      </geometry>
      <material name="">
        <color rgba="1 1 1 1" />
      </material>
    </visual>
    <collision>
      <origin xyz="0 0 0" rpy="0 0 0" />
      <geometry>
        <mesh filename="package://rosmemo/meshes/steering_angle.STL" />
      </geometry>
    </collision>
  </link>
  <joint name="steeringangleaxis" type="revolute">
    <origin xyz="0 0 0" rpy="0 0 0" />
    <parent link="base_link" />
    <child link="steering_angle" />
    <axis xyz="0 0 -1" />
    <limit lower="0" upper="0" effort="30" velocity="3" />
  </joint>
</robot>

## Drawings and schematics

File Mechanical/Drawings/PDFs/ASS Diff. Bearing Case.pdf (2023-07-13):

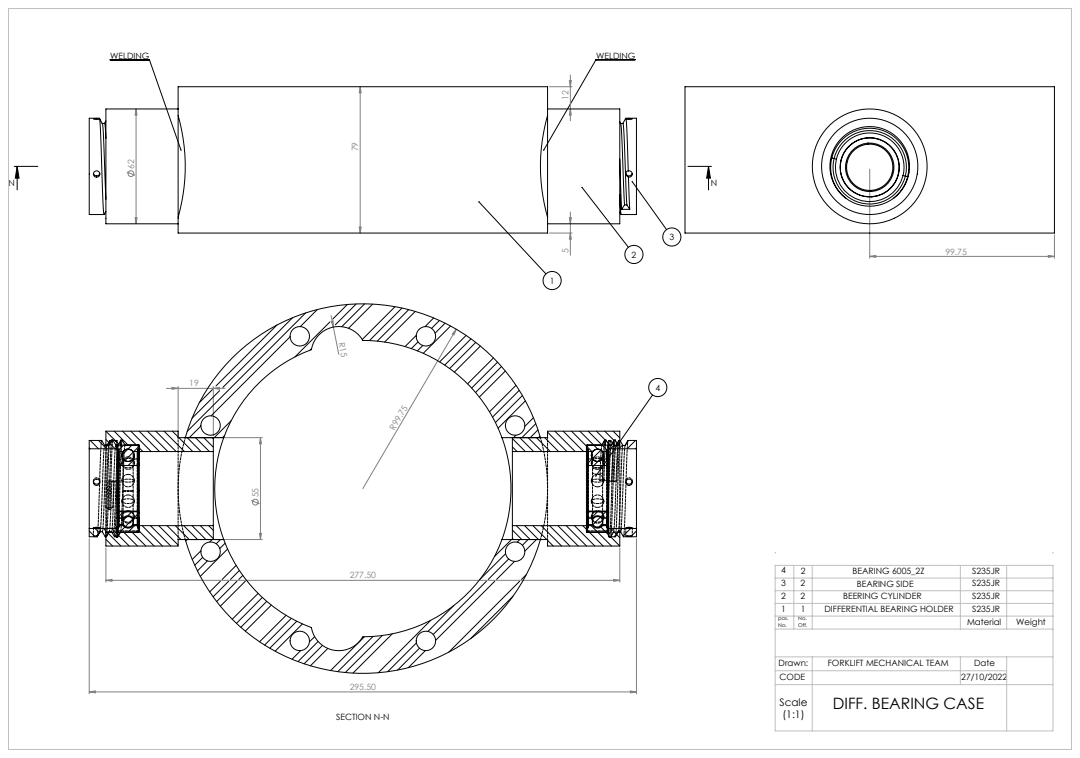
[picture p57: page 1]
SECTION N-N

4 | 2 | BEARING 6005_2Z | S235JR
3 | 2 | BEARING SIDE | S235JR
2 | 2 | BEERING CYLINDER | S235JR
1 | 1 | DIFFERENTIAL BEARING HOLDER | S235JR
pos. No. | Off. No. | | Material | Weight

Drawn: | FORKLIFT MECHANICAL TEAM | Date
CODE | | 27/10/2022
Scale (1:1) | DIFF. BEARING CASE

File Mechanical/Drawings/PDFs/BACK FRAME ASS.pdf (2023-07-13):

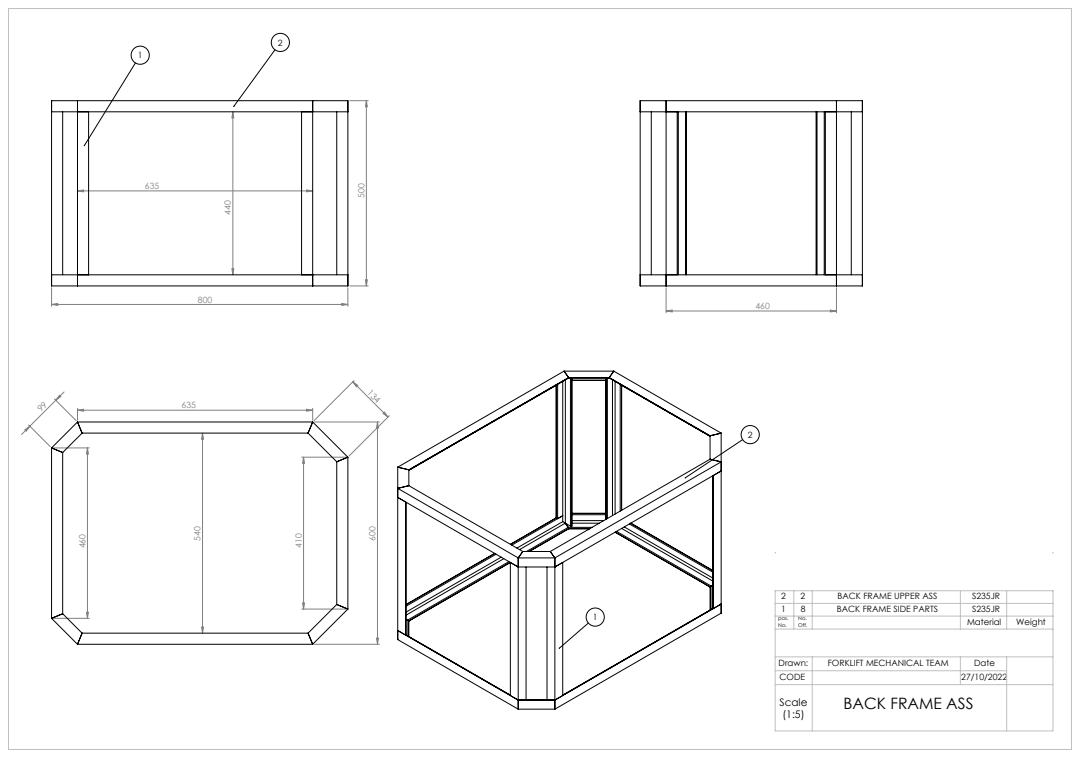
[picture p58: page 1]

2 | 2 | BACK FRAME UPPER ASS | S235JR
1 | 8 | BACK FRAME SIDE PARTS | S235JR
pos. No. | Off. No. | | Material | Weight

Drawn: | FORKLIFT MECHANICAL TEAM | Date
CODE | | 27/10/2022
Scale (1:5) | BACK FRAME ASS

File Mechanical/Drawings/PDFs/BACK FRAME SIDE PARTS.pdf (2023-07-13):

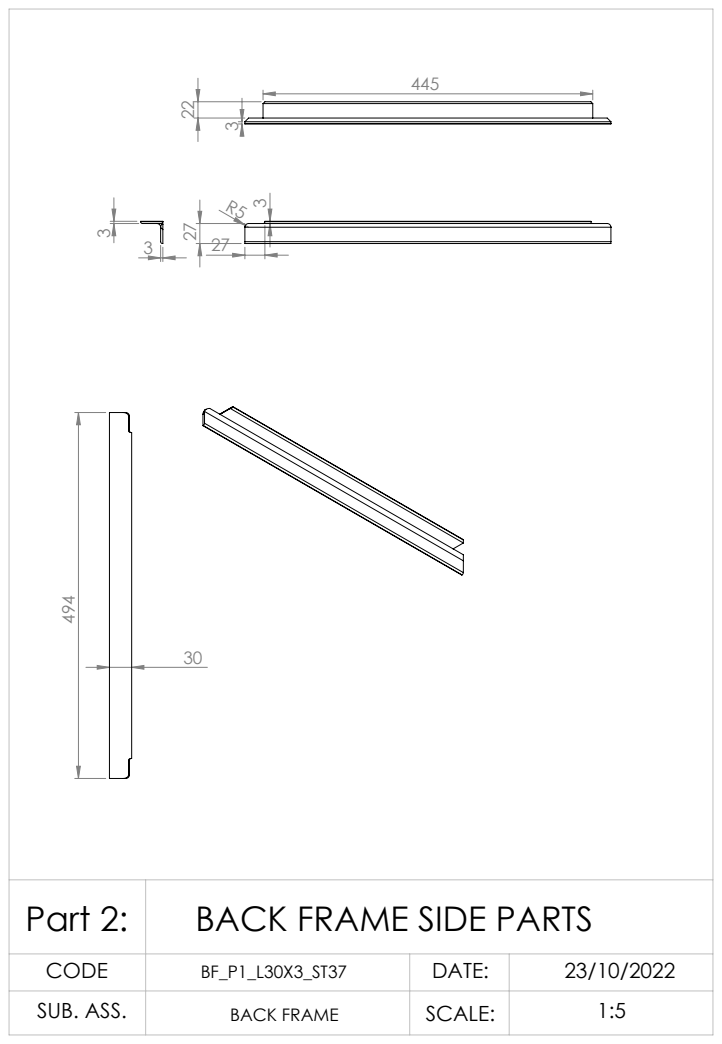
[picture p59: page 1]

Part 2: | BACK FRAME SIDE PARTS

CODE | BF_P1_L30X3_ST37 | DATE: | 23/10/2022
SUB. ASS. | BACK FRAME | SCALE: | 1:5

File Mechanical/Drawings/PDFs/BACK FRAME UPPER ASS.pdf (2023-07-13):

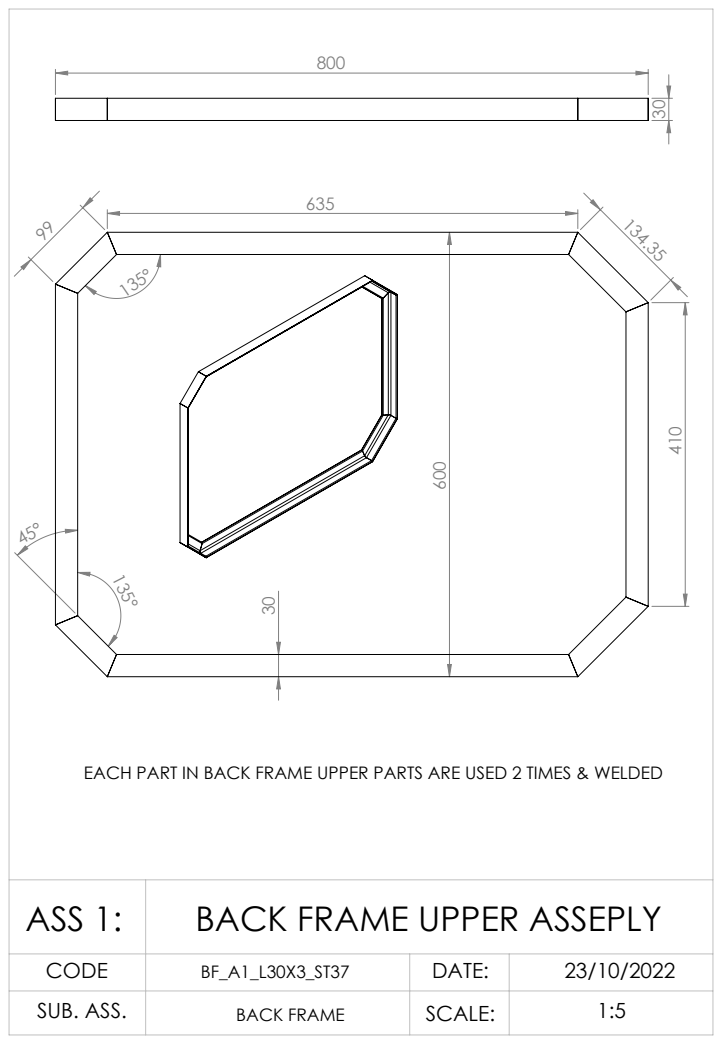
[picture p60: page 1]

EACH PART IN BACK FRAME UPPER PARTS ARE USED 2 TIMES & WELDED

ASS 1: | BACK FRAME UPPER ASSEPLY

CODE | BF_A1_L30X3_ST37 | DATE: | 23/10/2022
SUB. ASS. | BACK FRAME | SCALE: | 1:5

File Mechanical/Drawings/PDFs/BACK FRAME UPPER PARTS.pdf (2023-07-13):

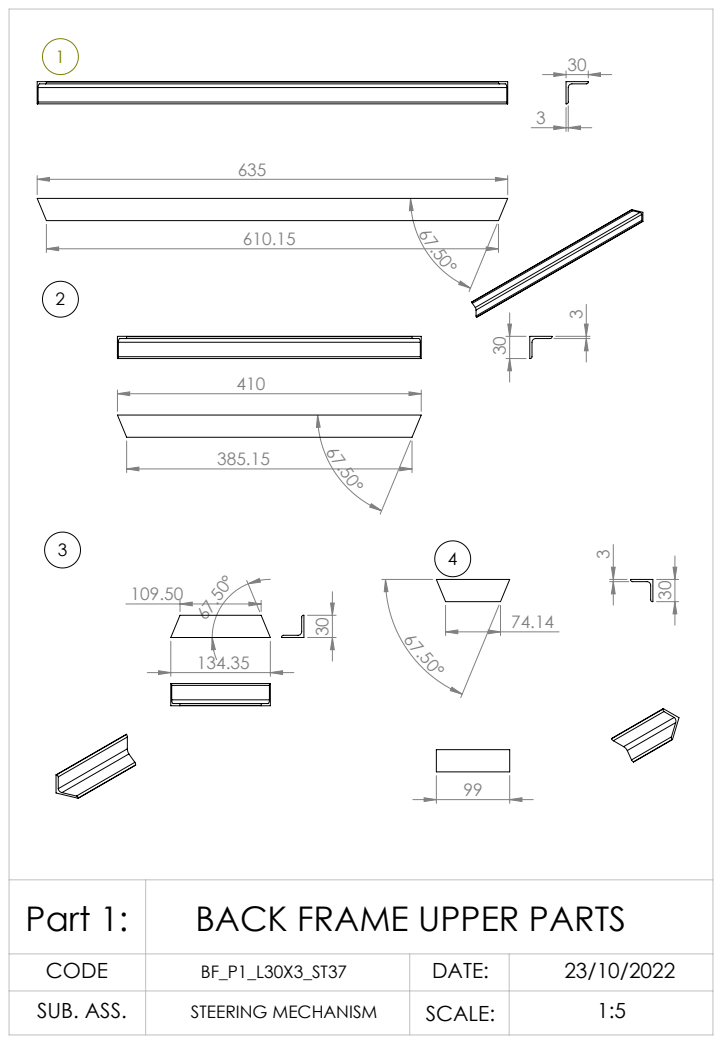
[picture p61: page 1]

Part 1: | BACK FRAME UPPER PARTS

CODE | BF_P1_L30X3_ST37 | DATE: | 23/10/2022
SUB. ASS. | STEERING MECHANISM | SCALE: | 1:5

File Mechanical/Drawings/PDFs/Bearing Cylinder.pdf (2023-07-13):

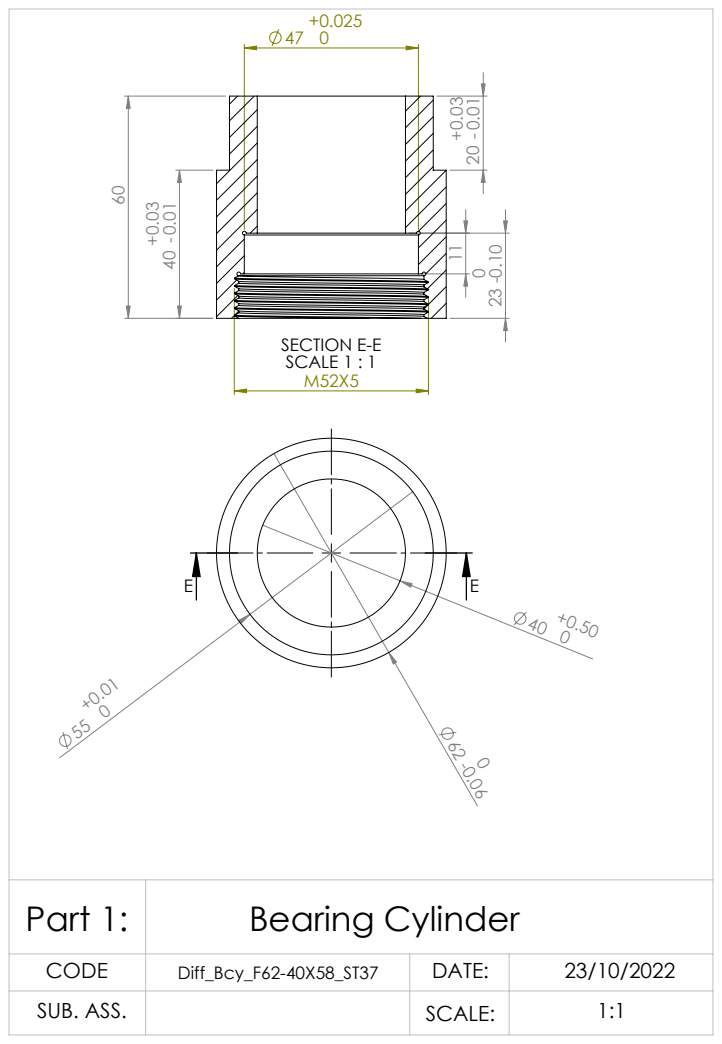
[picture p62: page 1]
SECTION E-E SCALE 1 : 1

Part 1: | Bearing Cylinder

CODE | Diff_Bcy_F62-40X58_ST37 | DATE: | 23/10/2022
SUB. ASS. | | SCALE: | 1:1

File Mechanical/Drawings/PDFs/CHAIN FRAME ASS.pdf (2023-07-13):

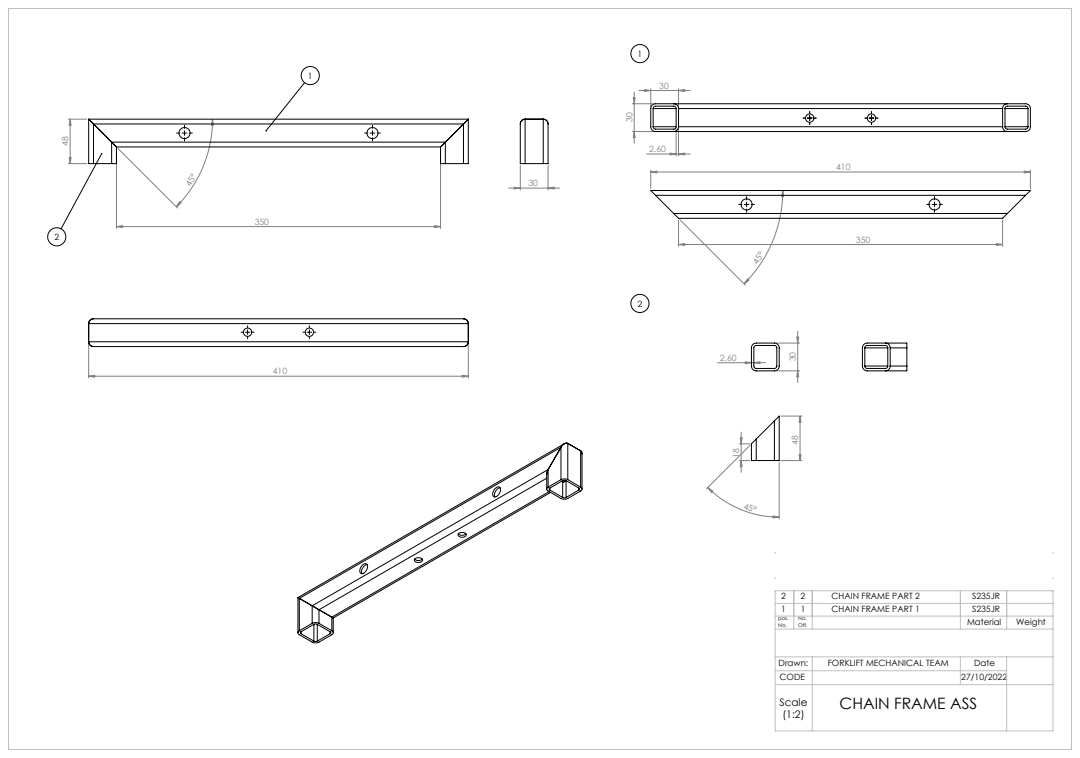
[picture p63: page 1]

2 | 2 | CHAIN FRAME PART 2 | S235JR
1 | 1 | CHAIN FRAME PART 1 | S235JR
pos. No. | Off. No. | | Material | Weight

Drawn: | FORKLIFT MECHANICAL TEAM | Date
CODE | | 27/10/2022
Scale (1:2) | CHAIN FRAME ASS

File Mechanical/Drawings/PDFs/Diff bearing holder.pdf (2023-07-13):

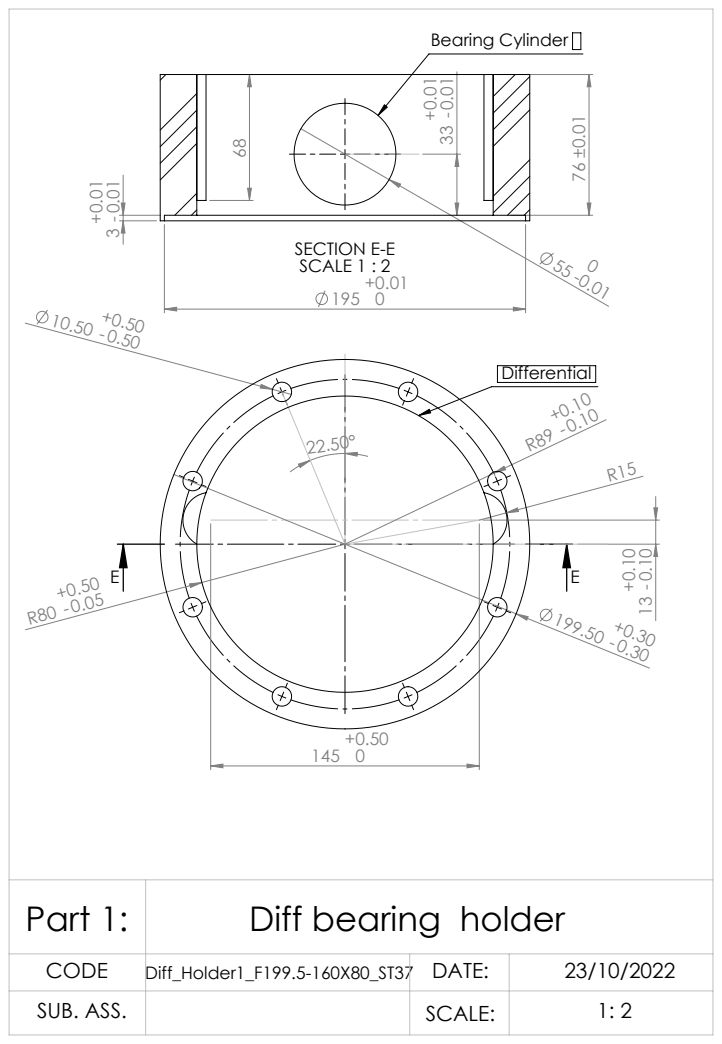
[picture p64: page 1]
SECTION E-E SCALE 1 : 2; Bearing Cylinder

Part 1: | Diff bearing holder

CODE | Diff_Holder1_F199.5-160X80_ST37 | DATE: | 23/10/2022
SUB. ASS. | | SCALE: | 1: 2

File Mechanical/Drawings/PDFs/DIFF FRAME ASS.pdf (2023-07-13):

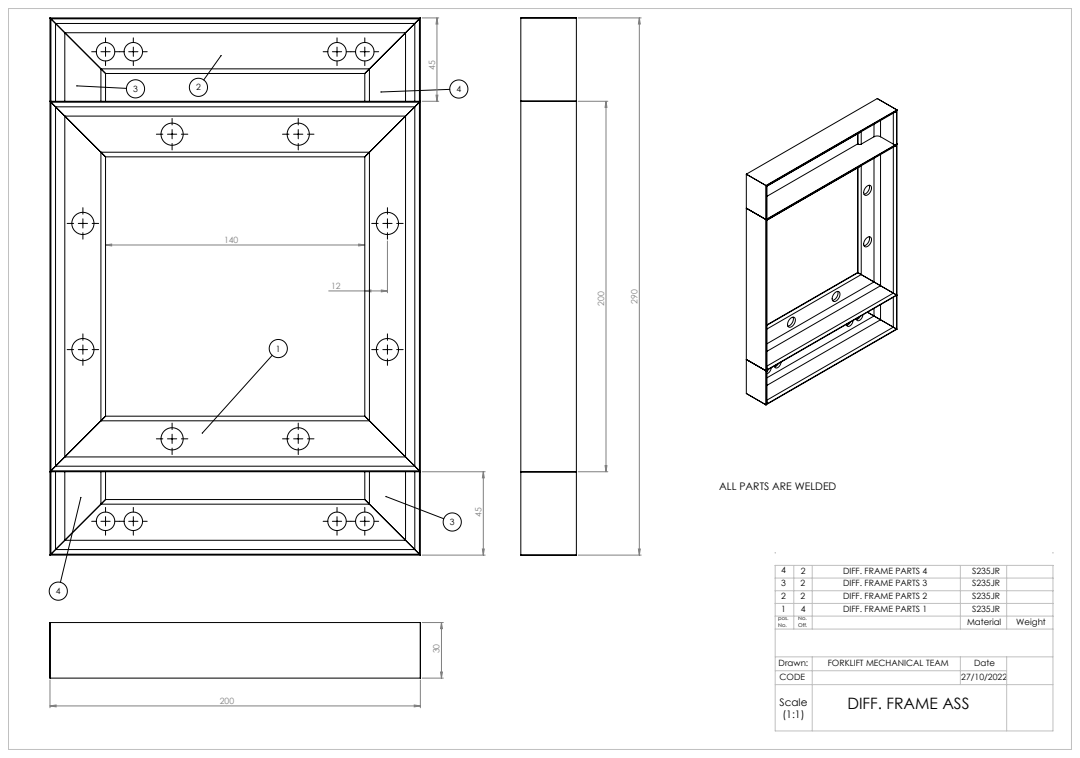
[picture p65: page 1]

ALL PARTS ARE WELDED

4 | 2 | DIFF. FRAME PARTS 4 | S235JR
3 | 2 | DIFF. FRAME PARTS 3 | S235JR
2 | 2 | DIFF. FRAME PARTS 2 | S235JR
1 | 4 | DIFF. FRAME PARTS 1 | S235JR
pos. No. | Off. No. | | Material | Weight

Drawn: | FORKLIFT MECHANICAL TEAM | Date
CODE | | 27/10/2022
Scale (1:1) | DIFF. FRAME ASS

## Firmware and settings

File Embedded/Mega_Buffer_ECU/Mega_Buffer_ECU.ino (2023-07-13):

#include <ros.h>
#include <std_msgs/Int16.h>
#include <std_msgs/Float64.h>
#include <geometry_msgs/Twist.h>


ros::NodeHandle nh;


std_msgs::Float64 right_wheel_tick_count;
ros::Publisher rightPub("right_ticks", &right_wheel_tick_count);

std_msgs::Float64 left_wheel_tick_count;
ros::Publisher leftPub("left_ticks", &left_wheel_tick_count);

//std_msgs::Float64  steering_setpoint;
//ros::Publisher steering_setpoint_pub("Steering_setpoint", &steering_setpoint);

double SetPoint = 0.0 ;

double STEERING_angle;

// Distance from center of the left tire to the center of the right tire in m
const double WHEEL_BASE_W = 0.429;

// Distance from the back axe to the front axe in m
const double WHEEL_BASE_H = 0.358;

char* formatDouble2(double value1 , double value2)
{
  static char str3[10];
  static char str1[10];
  static char str2[10];
  int intValue1 = (int)(value1 * 100);
  int intValue2 = (int)(value2 * 100);

  if ( value1 >= 10.0)
  {
    sprintf(str1, "+%02d%02d", intValue1 / 100, abs(intValue1 % 100));
  }
  else if (value1 > 0.0 && value1 < 10.0)
  {
    sprintf(str1, "+%02d%02d", intValue1 / 100, abs(intValue1 % 100));
  }
  else if (value1 < 0.0 && value1 > -1.0)
  {
    sprintf(str1, "-%02d%02d", intValue1 / 100, abs(intValue1 % 100));
  }
  else if (value1 <= -1.0)
  {
    sprintf(str1, "%03d%02d", intValue1 / 100, abs(intValue1 % 100));
  }

  if ( value2 >= 10.0)
  {
    sprintf(str2, "+%02d%02d\n", intValue2 / 100, abs(intValue2 % 100));
  }
  else if (value2 > 0.0 && value2 < 10.0)
  {
    sprintf(str2, "+%02d%02d\n", intValue2 / 100, abs(intValue2 % 100));
  }
  else if (value2 < 0.0 && value2 > -1.0)
  {
    sprintf(str2, "-%02d%02d\n", intValue2 / 100, abs(intValue2 % 100));
  }
  else if (value2 <= -1.0)
  {
    sprintf(str2, "%03d%02d\n", intValue2 / 100, abs(intValue2 % 100));
  }

  sprintf(str3, "*%s%s\n", str1, str2);
  return str3;
}

char* formatDouble1(double value)
{
  static char str[10];
  int intValue = (int)(value * 100);

  if ( value >= 10.0)
  {
    sprintf(str, "+%02d%02d\n", intValue / 100, abs(intValue % 100));
  }
  else if (value > 0.0 && value < 10.0)
  {
    sprintf(str, "+%02d%02d\n", intValue / 100, abs(intValue % 100));
  }
  else if (value < 0.0 && value > -1.0)
  {
    sprintf(str, "-%02d%02d\n", intValue / 100, abs(intValue % 100));
  }
  else if (value <= -1.0)
  {
    sprintf(str, "%03d%02d\n", intValue / 100, abs(intValue % 100));
  }
return str;

}


void get_linear_velocity(const geometry_msgs::Twist& cmdVel)
{
  if (cmdVel.angular.z != 0 && cmdVel.linear.x != 0) {
    SetPoint = (atan((cmdVel.angular.z) * (WHEEL_BASE_H / cmdVel.linear.x)));
    // SetPoint=1.0;
  }
  else if (cmdVel.angular.z == 0)
  {
    SetPoint = 0;
  }

  if (SetPoint <= -0.01 && SetPoint >= -0.03)
  {
    SetPoint = -0.01;
  }

  double input = SetPoint + 0.01;
  char* formattedString1 = formatDouble1(input);
  Serial1.print(formattedString1);


  double input1 = (cmdVel.linear.x / cos(STEERING_angle)) + 0.01;
  double input2 = STEERING_angle + 0.01;
  char* formattedString2 = formatDouble2(input1, input2);
  Serial2.print(formattedString2);
}

// Set up ROS subscriber to the velocity command
ros::Subscriber<geometry_msgs::Twist> subCmdVel("cmd_vel", &get_linear_velocity );

void setup()
{
  //  Serial.begin(115200);

  nh.getHardware()->setBaud(115200);
  nh.initNode();
  nh.advertise(rightPub);
  nh.advertise(leftPub);
  ////    nh.advertise(steering_setpoint_pub);
  nh.subscribe(subCmdVel);
  Serial1.begin(115200);
  Serial2.begin(115200);   // Configure the UART pins and baud rate
}

void loop()
{
  nh.spinOnce();
  //    Calc_Set_point();
  //  if (Serial.available() ) {
  //    // read the incoming byte:
  //    String input = Serial.readStringUntil('\n');// Read the input as a string
  //    double x = atof(input.c_str());
  //    SetPoint = x;
  //  }
  // STEERING_angle=0.0;
if (Serial1.available() ) {
    String input = Serial1.readStringUntil('\n'); // Read the input as a string
    double x = atof(input.c_str());
STEERING_angle = x/100.0;
  }


  if (Serial2.available() ) {
    String input = Serial2.readStringUntil('\n'); // Read the input as a string
    int number1, number2;
    sscanf(input.c_str(), "%d%d", &number1, &number2);
    right_wheel_tick_count.data = number1 - 1.0;
    left_wheel_tick_count.data = number2 - 1.0;
  }

  //  Serial.print(Right_Tick_recive);
  //  Serial.print("   ");
  //  Serial.print(Left_Tick_recive);
  //  Serial.print("   ");
  //  Serial.println(formattedString);

  leftPub.publish( &left_wheel_tick_count );
  rightPub.publish( &right_wheel_tick_count );
  ////    steering_setpoint_pub.publish(&steering_setpoint);

}

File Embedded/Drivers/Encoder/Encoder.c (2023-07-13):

/**********************************************************************************************************************
 *  FILE DESCRIPTION
 *  -----------------------------------------------------------------------------------------------------------------*/
/**        \file  FileName.c
 *        \brief
 *
 *      \details
 *
 *
 *********************************************************************************************************************/

/**********************************************************************************************************************
 *  INCLUDES
 *********************************************************************************************************************/
#include "Std_Types.h"
#include "Port.h"
#include "Dio.h"
#include "Port_Regs.h"
#include "Port_Cfg.h"
#include "Encoder.h"
#include "Encoder_Cfg.h"
#include "Uart.h"
#include "Gptm.h"
#include "tm4c123gh6pm_registers.h"
/**********************************************************************************************************************
 *  LOCAL MACROS CONSTANT\FUNCTION
 *********************************************************************************************************************/

/**********************************************************************************************************************
 *  LOCAL DATA
 *********************************************************************************************************************/

/**********************************************************************************************************************
 *  GLOBAL DATA
 *********************************************************************************************************************/
STATIC const Encoder_ConfigChannel * Encoder_Configuration1 = NULL_PTR;
STATIC const Encoder_ConfigChanne2 * Encoder_Configuration2 = NULL_PTR;
volatile long encoder_pos =0;
unsigned int IntCtrl_Status = 0;

STATIC uint8 Encoder_Status = ENCODER_NOT_INITIALIZED;
extern float32 measurement;

float Right_Ticks = 0.0 ;
float Left_Ticks = 0.0 ;

float Size_FLoat;
int Size_Int_Left;
int Size_Int_Right ;
extern float32 SetPoint_S ;

extern float Numbers_Send_esp_1;
extern float Numbers_Send_esp_2;

extern char sending_buffer_1[11] ;

// Number of ticks a wheel makes moving a linear distance of 1 meter
const double TICKS_PER_RAD = 1031.0;
const double TICKS_PER_METER = 850;

// Distance from center of the left tire to the center of the right tire in m
const double WHEEL_BASE_W = 0.429;

const double WHEEL_BASE_H = 0.358;

double distance ;
double delta_t;

double velWheel ;
int prevWheelCount;
double prevTime ;

float Result_Value[361]= {0.599162011173185, 0.607865732418108, 0.61652316233406, 0.625133641624234, 0.633696514567294, 0.642211129067315, 0.650676836703436, 0.659092992779244, 0.667458956371869, 0.675774090380795, 0.684037761576372, 0.692249340648045, 0.700408202252275, 0.708513725060164, 0.716565291804766, 0.724562289328103, 0.73250410862785, 0.74039014490372, 0.748219797603519, 0.755992470468879, 0.763707571580669, 0.77136451340407, 0.778962712833316, 0.786501591236102, 0.793980574497651, 0.801399093064432, 0.808756581987532, 0.816052480965687, 0.82328623438794, 0.830457291375961, 0.837565105825999, 0.844609136450463, 0.851588846819148, 0.858503705400088, 0.86535318560003, 0.872136765804538, 0.878853929417714, 0.885504164901544, 0.892086965814848, 0.89860183085185, 0.905048263880354, 0.911425773979527, 0.917733875477283, 0.92397208798727, 0.930139936445454, 0.936236951146294, 0.942262667778516, 0.948216627460467, 0.954098376775068, 0.959907467804335, 0.965643458163497, 0.971305911034678, 0.976894395200171, 0.982408485075268, 0.987847760740678, 0.993211807974499, 0.998500218283768, 1.00371258893556, 1.00884852298768, 1.01390762931885, 1.01888952265855, 1.02379382361631, 1.02862015871062, 1.03336816039738, 1.03803746709788, 1.04262772322633, 1.04713857921696, 1.05156969155063, 1.05592072278096, 1.06019134156009, 1.06438122266386, 1.06849004701661, 1.07251750171545, 1.07646328005412, 1.08032708154631, 1.08410861194858, 1.08780758328276, 1.09142371385785, 1.09495672829151, 1.09840635753102, 1.10177233887375, 1.10505441598719, 1.10825233892845, 1.11136586416334, 1.11439475458484, 1.11733877953122, 1.12019771480359, 1.12297134268296, 1.12565945194682, 1.12826183788525, 1.13077830231648, 1.133208653602, 1.13555270666115, 1.13781028298522, 1.13998121065103, 1.14206532433403, 1.1440624653209, 1.14597248152162, 1.14779522748105, 1.14953056439004, 1.15117836009597, 1.1527384891128, 1.15421083263069, 1.15559527852495, 1.15689172136469, 1.15810006242076, 1.15922020967331, 1.16025207781879, 1.16119558827644, 1.1620506691943, 1.16281725545463, 1.16349528867893, 1.16408471723235, 1.16458549622761, 1.16499758752845, 1.16532095975253, 1.16555558827381, 1.1657014552244, 1.16575854949599, 1.16572686674061, 1.16560640937103, 1.16539718656055, 1.1650992142423, 1.16471251510802, 1.16423711860634, 1.16367306094055, 1.16302038506583, 1.16227914068598, 1.16144938424961, 1.16053117894589, 1.15952459469972, 1.15842970816638, 1.15724660272573, 1.15597536847581, 1.15461610222604, 1.15316890748981, 1.1516338944766, 1.15001118008359, 1.14830088788677, 1.14650314813151, 1.14461809772266, 1.14264588021409, 1.14058664579781, 1.13844055129249, 1.13620776013154, 1.13388844235065, 1.13148277457484, 1.12899094000504, 1.12641312840409, 1.12374953608233, 1.12100036588262, 1.11816582716492, 1.11524613579032, 1.11224151410464, 1.10915219092143, 1.10597840150463, 1.10272038755059, 1.09937839716968, 1.09595268486741, 1.09244351152503, 1.08885114437968, 1.08517585700403, 1.08141792928544, 1.07757764740466, 1.07365530381401, 1.06965119721515, 1.06556563253631, 1.06139892090903, 1.05715137964456, 1.0528233322096, 1.04841510820173, 1.04392704332425, 1.0393594793607, 1.03471276414876, 1.02998725155377, 1.02518330144181, 1.0203012796523, 1.01534155797008, 1.01030451409717, 1.00519053162395, 1.0 ,0.994733314504391, 0.989390876215617, 0.983973091981036, 0.978480374385893, 0.972913141721901, 0.96727181795538, 0.961556832694976, 0.955768621158945, 0.949907624142003, 0.943974287981766, 0.937969064524754, 0.931892411091984, 0.925744790444141, 0.919526670746338, 0.913238525532467, 0.906880833669129, 0.900454079319175, 0.893958751904832, 0.887395346070429, 0.880764361644732, 0.874066303602877, 0.867301682027919, 0.860471012071978, 0.85357481391702, 0.846613612735232, 0.839587938649037, 0.832498326690716, 0.82534531676167, 0.818129453591299, 0.810851286695519, 0.803511370334919, 0.796110263472547, 0.788648529731345, 0.781126737351228, 0.773545459145806, 0.765905272458767, 0.758206759119908, 0.750450505400825, 0.742637101970268, 0.73476714384916, 0.726841230365281, 0.718859965107629, 0.710823955880455, 0.702733814656974, 0.694590157532762, 0.686393604678839, 0.678144780294439, 0.669844312559475, 0.661492833586702, 0.653090979373577, 0.644639389753829, 0.636138708348728, 0.627589582518075, 0.618992663310902, 0.61034860541589,
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

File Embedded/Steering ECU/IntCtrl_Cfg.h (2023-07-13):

/**********************************************************************************************************************

 *  FILE DESCRIPTION
 *  -------------------------------------------------------------------------------------------------------------------
 *         File:  IntCtrl_Cfg.h
 *       Module:  Nested Vector Interrupt Configration
 *
 *  Description:  Port Configuration Header file     
 *  
 *********************************************************************************************************************/
#ifndef INTCTRL_CFG_H
#define INTCTRL_CFG_H

/**********************************************************************************************************************
 * INCLUDES
 *********************************************************************************************************************/


/**********************************************************************************************************************
 *  GLOBAL CONSTANT MACROS
 *********************************************************************************************************************/
#define INTCTRL_CONFIGURED_INTERRUPT  (3U)
						
/* Interrupt Group Priority Number */
#define INTCTRL_GROUP0	(0U)
#define INTCTRL_GROUP1	(1U)
#define INTCTRL_GROUP2	(2U)
#define INTCTRL_GROUP3	(3U)
#define INTCTRL_GROUP4	(4U)
#define INTCTRL_GROUP5	(5U)
#define INTCTRL_GROUP6	(6U)
#define INTCTRL_GROUP7	(7U)

/* Interrupt Sub Group Priority Number */
#define INTCTRL_SUBGROUP0	(0U)
#define INTCTRL_SUBGROUP1	(1U)
#define INTCTRL_SUBGROUP2	(2U)
#define INTCTRL_SUBGROUP3	(3U)
#define INTCTRL_SUBGROUP4	(4U)
#define INTCTRL_SUBGROUP5	(5U)
#define INTCTRL_SUBGROUP6	(6U)
#define INTCTRL_SUBGROUP7	(7U)

/* Fixed Group Priority Number */
#define RESET_GROUP_PRIORITY                     (-3)
#define NON_MASKABLE_INTERRUPT_GROUP_PRIORITY    (-2)
#define HARD_FAULT_GROUP_PRIORITY                (-1)

/* Fixed Sub-Group Priority Number */
#define RESET_SUP_GROUP_PRIORITY                     (-3)
#define NON_MASKABLE_INTERRUPT_SUP_GROUP_PRIORITY    (-2)
#define HARD_FAULT_SUP_GROUP_PRIORITY                (-1)

/* Write and Read(VECTKEY)Bits in order to change the bits in this register.*/
#define INTCTRL_VALUE_TO_WRITE_NUMBER  0x05FA
#define INTCTRL_VALUE_TO_READ_NUMBER   0xFA05

/* Shift Bit In Register (VECTKEY) & (PRIGROUP) */
#define APINT_VECTKEY_NUM  (16)
#define APINT_PRIGROUP_NUM  (8)

/* Interrupt Priority Levels Group And Sub-Group */
#define NVIC_PRIORITY_GROUPS_7_SUB_0                     0x4
#define NVIC_PRIORITY_GROUPS_0_SUB_7                     0x7
#define NVIC_PRIORITY_GROUPS_3_SUB_1                     0x5
#define NVIC_PRIORITY_GROUPS_1_SUB_3                     0x6

/* Macros for IntCtrl Status */
#define INTCTRL_INITIALIZED                (1U)
#define INTCTRL_NOT_INITIALIZED            (0U)

#define PRIX_INTA_NUM      (5)
#define PRIX_INTB_NUM      (13)
#define PRIX_INTC_NUM      (21)
#define PRIX_INTD_NUM      (29)

#define REG_LENGTH_BIT   32
#define REG_LENGTH_BYTE  4

/* Enable Exceptions */
#define Enable_Exceptions()    __asm("CPSIE I")

/* Disable Exceptions */
#define Disable_Exceptions()   __asm("CPSID I")

/* Enable Faults */
#define Enable_Faults()        __asm("CPSIE F")

/* Disable Faults */
#define Disable_Faults()       __asm("CPSID F") 

/* Go to low power mode while waiting for the next interrupt */
#define Wait_For_Interrupt()   __asm("WFI")


/**********************************************************************************************************************
 *  GLOBAL FUNCTION MACROS
 *********************************************************************************************************************/


/**********************************************************************************************************************
 *  GLOBAL DATA TYPES AND STRUCTURES
 *********************************************************************************************************************/


/**********************************************************************************************************************
 *  GLOBAL DATA PROTOTYPES
 *********************************************************************************************************************/

 
/**********************************************************************************************************************
 *  GLOBAL FUNCTION PROTOTYPES
 *********************************************************************************************************************/

 
#endif  /* INTCTRL_CFG.H */

/**********************************************************************************************************************
 *  END OF FILE: Std_Types.h
 *********************************************************************************************************************/

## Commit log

2023-07-13 Embedded (Drivers ECUs)
2023-07-13 Jetson Data (Navigation & Localization & Vision)
2023-07-13 Forklift's Mechanical Data
    [06B-1(2).step.SLDPRT, 06B-1.step.SLDPRT, 10inWheel.SLDPRT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]
2023-07-13 Forklift's Modelling Data
    [Magic.SLDPRT, offset.SLDPRT, sim2.SLDPRT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]
2023-07-13 Forklift's Vision Data
    [yolov2-tiny-voc.cfg, yolov2-tiny.cfg, yolov2-voc.cfg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]
2023-07-14 PID Driver
2023-07-24 URDF -> (arviz & gazibo)
    [left_wheel.STL, model.sdf, right_wheel.STL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]
